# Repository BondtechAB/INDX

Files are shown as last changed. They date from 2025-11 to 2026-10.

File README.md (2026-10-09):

# INDX Wiki

> The community knowledge base for the Bondtech INDX, an induction-based automatic tool changer for open-platform XY-head 3D printers.

---

## Table of Contents

**Part 1: What is INDX?**

1. [What is INDX?](#what-is-indx)
2. [How It Works](#how-it-works)
3. [Kits & What's in the Box](#kits--whats-in-the-box)
4. [Supported Printers](#supported-printers)
5. [Technical Specifications](#technical-specifications)
   - [Part Cooling](#part-cooling)

**Part 2: Getting Started**

6. [Requirements & Preparation](#requirements--preparation)
7. [Installation](#installation)
   - [Hardware Installation](#hardware-installation)
   - [Firmware Configuration](#firmware-configuration)
     - [Klipper / Kalico](#klipper)
       - [INDX macro files](#indx-macro-files)
       - [Required Klipper sections](#required-klipper-sections)
       - [Load cell probe](#load-cell-probe)
       - [Automated dock X measurement](#automated-dock-x-measurement-built-in)
       - [Homing override](#homing-order-important)
         - [Seat check](#seat-check)
     - [RRF (RepRapFirmware)](#rrf-reprapfirmware)
   - [Initial Startup](#initial-startup)

**Part 3: Configuration**

8. [Configuration](#configuration)
   - [Dock Position Calibration](#dock-position-calibration)
     - [Finding dock_y](#finding-dock_y-y-fully-seated-position)
     - [Finding dock_x](#finding-dock_x-x-tool-centre)
   - [Tool Offsets](#tool-offsets)
     - [Method 1: Print and adjust](#method-1-print-and-adjust-free-no-extra-hardware)
     - [Method 2: Nudge](#method-2-nudge-automatic-requires-small-hardware)
     - [Method 3: Nozzle camera + CAL_ONE/TWO/THREE](#method-3-nozzle-camera-most-precise-xy-higher-cost)
     - [Z offset: CAL_Z](#z-offset-calibration)
   - [Temperature & Induction Settings](#temperature--induction-settings)
   - [Speed & Acceleration](#speed--acceleration)

**Part 4: Day-to-day Use**

9. [Using INDX](#using-indx)
   - [Loading Filament into Tools](#loading-filament-into-tools)
   - [Performing Tool Changes](#performing-tool-changes)
   - [Slicer Setup](#slicer-setup)

**Part 5: Designing for INDX**

10. [Designing for INDX](#designing-for-indx)
    - [Dock Design](#dock-design)
    - [Part Cooling (custom)](#part-cooling-1)
    - [CAD Files & Templates](#cad-files--templates)

**Part 6: Maintenance, Support & Community**

11. [Maintenance](#maintenance)
    - [Nozzle clog: cold pull procedure](#nozzle-clog-cold-pull-procedure)
12. [Troubleshooting](#troubleshooting)
13. [FAQ](#faq)
14. [Community & Contributing](#community--contributing)

---

**Part 1: What is INDX?**

---

## What is INDX?

INDX (INduction Dynamic eXtruder) is Bondtech's automatic tool-changer system for FDM 3D printers. It enables printing with multiple materials, colors, or nozzle sizes in a single print, with near-zero purge waste and tool changes in around 14 seconds. Run two tools or ten; scale your setup as far as your build space allows.

Unlike filament-switcher systems, INDX is a true tool changer: each tool carries its own filament directly. There is no shared filament path and no purge block required.

Unlike traditional mechanical tool changers, INDX uses wireless induction heating, so the passive tools contain **no wires, no heaters, no thermistors, and no electronics**. This makes each tool dramatically cheaper and mechanically simpler.

INDX is sold by Bondtech as a **Development Kit** for open CoreXY printers. Prusa Research has built an official first-party integration for the **CORE One** and **CORE One L**, sold directly through Prusa.

| | INDX Development Kit | Prusa CORE One / CORE One L |
|---|---|---|
| **Sold by** | Bondtech ([bondtech.se](https://www.bondtech.se)) | Prusa Research ([prusa3d.com](https://www.prusa3d.com)) |
| **For** | Most CoreXY printers with open firmware | Prusa CORE One / CORE One L |
| **Setup** | Self-managed (community-supported) | Plug-and-play |
| **Smart Head** | See [bondtech.se](https://www.bondtech.se) | See [prusa3d.com](https://www.prusa3d.com/applications/prusa-3d-printers-with-bondtech-indx_243519/) |
| **Passive Tools** | See [bondtech.se](https://www.bondtech.se) | See [prusa3d.com](https://www.prusa3d.com/applications/prusa-3d-printers-with-bondtech-indx_243519/) |

This wiki focuses on the **INDX Development Kit** and community integrations. For the Prusa integration, refer to [Prusa's documentation](https://www.prusa3d.com/applications/prusa-3d-printers-with-bondtech-indx_243519/).

---

## How It Works

INDX is built around two components: a single active **Smart Head** that stays on the gantry, and a set of interchangeable **Thin Passive Tools** parked in a dock.

### Smart Head

The single active unit that travels on the gantry. Contains all expensive and active components:

- **Induction coil (IN)**: wirelessly heats the nozzle of whichever passive tool is currently mounted on the Smart Head.
- **IR thermopile sensor**: reads nozzle temperature without physical contact. Also reports ambient temperature and nozzle surround temperature for monitoring.
- **Dynamic eXtruder (DX)**: self-adjusting dual-drive extruder with automatic tension mechanism.
- **Load cell**: used for sensing tool/nozzle touch.
- All wiring, electronics, and motion stays here; nothing transfers to the passive tools

### Thin Passive Tools

Interchangeable tools parked in a dock within reach of the gantry. Each tool contains a filament path and a specially designed nozzle, and nothing else. No wires, no heaters, no thermistors, no electronics. Heat is delivered wirelessly by the Smart Head's induction coil when the tool is picked up; the tool cools passively when deposited back in the dock.

Two variants are available, both built from steel:

- **CHT (Core Heating Technology)**: splits filament into three strands internally for faster melting and higher flow rates. The standard choice for most materials except abrasive materials. Available in common sizes.
- **Standard (non-CHT)**: straight-through melt zone with lower back-pressure, optimized for soft flexible filaments (TPU, TPE).

Tools are held in the Smart Head by a high-precision **Maxwell coupling** (a 3-point kinematic coupling that self-aligns the tool to the exact same position every time it is picked up), ensuring micron-level repeatability on every tool change. In practice this means you calibrate your tool offsets once, and they stay correct across thousands of tool changes.

### Tool Change Sequence

1. Smart Head moves to the dock and deposits the current tool
2. Smart Head picks up the next tool
3. Induction coil heats the new nozzle to printing temperature (~4-10 seconds)
4. Printing resumes

**Total tool change time: ~14 seconds**, depending on temperature delta, priming, and travel distance.

Because every material runs in its own dedicated nozzle, there is no cross-contamination between materials; purging is not required. The only material used after a tool change is a small **prime** at the start of printing: when a nozzle heats up, the filament in the melt zone re-melts and pressure needs to be rebuilt before extrusion is consistent. Priming pushes a small amount of filament through to establish that pressure, ensuring the first line of print is correctly extruded. Because each tool also cools passively when separated from the Smart Head, oozing is minimal.

---

## Kits & What's in the Box

### Development Kit

The INDX Development Kit comes as a **base kit** (the core hardware you need to get started) plus **tools** and **accessories** you choose to match your printer and setup.

#### What's in the box

Every Development Kit includes:

| Component | Description |
| --- | --- |
| **Bondtech INDX Smart Head** | The active unit: induction coil, contactless IR temperature sensor, DX extruder, and all electronics. One per printer. **Does not include a Thin Passive Tool**; tools are ordered separately. |
| **Bondtech INDX Link Board** | USB/CAN bridge between your host computer and the Smart Head. Includes 330 mm AWG18 power cables with horseshoe connectors for PSU screw terminals. A USB cable from the Link Board to your host is not included; see [Link Board](#link-board) for requirements. |
| **Crimp & connector kit** | Crimps and connectors for terminating accessories to the Bondtech INDX PCB: part cooling fan, LED, endstop, and USB devices. |

#### Tools

Thin Passive Tools are the interchangeable tool heads that do the actual printing. Choose quantity, nozzle type, and nozzle size when ordering. You need at least one tool to print, and one per material or color you want to run simultaneously.

| Option | Nozzle sizes | Best for |
| --- | --- | --- |
| **CHT (Core Heating Technology)** | 0.4 / 0.5 / 0.6 / 0.8 / 1.0mm | Most materials: PLA, PETG, ABS, ASA, TPU, TPE, PVA, BVOH, HIPS, PC, Nylon, PP, PBT, unfilled PC blends, and other non-abrasive filaments |
| **Standard (non-CHT)** | 0.25 / 0.4mm | Flexible filaments (TPU, TPE) and sensitive composites |

See [Thin Passive Tools](#thin-passive-tools) in the Technical Specifications for full details on each variant.

#### Accessories

Select the accessories that match your printer when ordering:

| Accessory | Options | Notes |
| --- | --- | ----- |
| **Bondtech INDX Link Cable** | Choose length | XT30 2+2 cable (24V, GND, CAN+, CAN−) with a shield connected to GND on the Link Board, from the Link Board to the Smart Head. Red/black wires carry power, yellow/white carry CAN H/L. Choose the length that fits your wiring run. See note below. |
| **Tool Dock** | Pre-made SLS hardware or STL/STEP files | Bondtech's ready-made docks are designed for MakerBeam XL 15×15. Or download the files and print your own; the standard 1515 body suits both profiles. |
| **X-Carriage adapter** | MGN12H option for 6mm belts, or download files | Required to mount the Smart Head to your carriage. Available for common CoreXY standards; check the shop or download from GitHub. |

> **What is CAN bus?** CAN bus is a communication standard that lets multiple devices share a single cable. You don't need to understand the protocol in depth; the Link Board handles it for you. In practice it means the Smart Head connects to the Link Board via just one 4-wire cable (carrying both power and data) instead of the bundle of wires a conventional toolhead needs. CAN is currently only supported on RRF; USB is used for Klipper/Kalico.
>
> **Choosing cable length:** Measure the wiring run from your Link Board mounting location to the Smart Head along the actual path the cable will travel (over the gantry, not straight-line). Add some slack. When in doubt, order longer. A cable that is too short cannot be extended, and excess length can be coiled and managed.

> **Integration note:** The Development Kit does not include a pre-configured printer profile or plug-and-play setup. You are responsible for integrating INDX with your printer's firmware and mechanics. The community provides configs and guides for common platforms; see [Supported Printers](#supported-printers) and [Community & Contributing](#community--contributing).

---

## Supported Printers

### First-party integrations

Prusa Research has built an official first-party integration for their CoreXY printers. These are sold and supported directly by Prusa, not through the INDX Development Kit.

| Printer | Status | Notes |
| --- | --- | ----- |
| Prusa CORE One | Available | Sold by Prusa Research. Plug-and-play. Supports up to 8 tools. See [prusa3d.com](https://www.prusa3d.com/applications/prusa-3d-printers-with-bondtech-indx_243519/) for details. |
| Prusa CORE One L | Coming later | First-party Prusa integration, availability timeline TBD. Supports up to 8 tools. |

### Officially recognized integrations

Beyond the first-party Prusa integration, a few community-built integrations are solid enough that Bondtech points people at them by name. Each comes with ready-to-print parts and the installation files needed to mount INDX on that machine.

They are not Bondtech products. They are hosted externally and maintained by their designers, so questions about the parts themselves belong with them rather than in this repository. Recognized here means we rate the work, not that we support it.

| Printer | Designer | Files |
| --- | --- | ----- |
| Sovol SV08 OG & SV08 Max | 3DPrintDemon | [Printables](https://www.printables.com/model/1771164-official-indx-sovol-sv08-og-sv08-max-integrations) |
| Voron Trident R2 | Steve — Voron team, designer of the Trident | [Printables](https://www.printables.com/model/1761163-trident-r2-bondtech-indx-mods) |

### Unverified community builds

INDX runs on a wide range of CoreXY printers, far more than Bondtech could ever test and support directly. What makes that possible is community members who've done the integration work on their own printer and shared what they learned. The printers below are known to work; what varies is whether anyone has published parts for them yet.

> ⚠️ **Nothing in this table has been checked by Bondtech.** We have not printed these parts, measured them, or run them on a machine here. Listing a build is not an endorsement and says nothing about whether the geometry is right. Read them the way you would read any stranger's remix: check a dock against [Dock Design](#dock-design) before printing it, since dock geometry that misses those constraints gives unreliable tool changes rather than an obvious failure. Questions about these parts belong with whoever made them, not with Bondtech.

| Printer | Build | Source |
| --- | ----- | --- |
| Voron 2.4 | Full conversion parts set: X-carriage, tool holder, XY joint, front idlers, Z bearing block with Y endstop, Z chain mount | [karasgit/INDX-for-Voron-2.4](https://github.com/karasgit/INDX-for-Voron-2.4), with a [walkthrough video](https://www.youtube.com/watch?v=topIOL-b3Gw) by Emplikac 000 |
| RatRig V-Core | None published yet | — |
| Custom CoreXY | None, and none expected: mounting is specific to your machine | Any CoreXY with open firmware works; see [Requirements](#requirements--preparation) |

The [Bondtech Discord](https://discord.gg/XDX9jDXN6e) has channels for specific printers, which is the best place to find someone running the same platform and ask how far along they got.

**Your printer isn't listed?** If you've got INDX running on it, that integration belongs here. Submit a pull request on [github.com/BondtechAB/INDX](https://github.com/BondtechAB/INDX) and you'll save the next person hours of work. See [Contributing a printer integration](#contributing-a-printer-integration) for what to include.

---

## Technical Specifications

*Specifications are preliminary and subject to change.*

### Smart Head

| Specification | Value |
| --- | ----- |
| Maximum operating voltage | 24V |
| Maximum nozzle temperature | 300°C |
| Maximum ambient operating temperature | 60°C |
| Flow rate | 40mm³/s *(measured at 220°C with 25°C ambient; lower rates achievable depending on nozzle size)* |
| Nozzle heat-up time | ~4-8 seconds |
| Tool change time | ~14 seconds *(highly dependent on temperature, priming, and travel distance)* |
| Power consumption | ~60W |
| Tool change mechanism | Maxwell coupling (3-point kinematic) |
| Heater type | Induction coil |
| Temperature sensor | Wireless & contactless IR thermopile |
| Nozzle sensor | Load cell (bi-directional) |
| Extrusion system | Direct Drive |
| Filament pre-tension | Self-adjusting (DX extruder, dual-drive with automatic tensioning) |
| Extruder chassis material | Aluminium |
| Cowling material | SLS-printed PA12 |
| Minimum tool center-to-center distance | 34mm bare; **41mm** with Bondtech part cooling solutions |
| Weight | 345g *(including one tool)* |
| Dimensions | See [reference geometry](#cad-files--templates) |

### Part Cooling

INDX uses a modular part cooling system. Cooling solutions snap onto the outside of the Smart Head cowlings, making it easy to swap between setups without tools. Three options are supported:

| Option | Description |
| --- | --- |
| **Dual 40×10 fans** | Two radial blower fans mounted symmetrically for balanced airflow around the nozzle |
| **CPAP** | High-flow airflow from a remote CPAP blower unit, routed via a flexible tube to the Smart Head, keeping weight off the gantry |

The right choice depends on your materials and print speed requirements. The dual 40×10 connect to the part cooling fan output on the Bondtech INDX PCB. The CPAP blower is a remote unit mounted elsewhere on the printer and connects to your main board instead; only the airflow tube routes to the Smart Head.

Printable ducts for both options are available in [CAD Files & Templates](#cad-files--templates).

### Bondtech INDX PCB

The Bondtech INDX PCB is mounted inside the Smart Head and is the central electronics board for the system.

**Electronics**

| Specification | Value |
| --- | ----- |
| Stepper driver | TMC2240 |
| Stepper run current | 0.6A |
| Extruder rotation distance | 5.7mm |
| Built-in accelerometer | LIS2DW |
| Built-in rotary encoder | AS5047D (magnetic) |
| Built-in load cell | *(specifications to be confirmed)* |

**Connectors**

| Connector | Pins | Notes |
| --- | ---- | ----- |
| Motor | Coil A+, Coil A−, Coil B+, Coil B− | DX extruder stepper motor |
| Fan | TACHO, FAN+, GND | Supports tachometer feedback |
| LED | 5V (VBUS), NP OUT, GND | NeoPixel compatible |
| Endstop | 3V3, SIGNAL, GND | 3.3V logic level |
| USB | VBUS, DP+, DP−, GND, GND | Supports accessories such as camera or Beacon probe scanner. **The DP+/DP− silkscreen is swapped — see [USB data pins](#usb-data-pins-are-swapped)** |
| CAN termination jumper | — | Enable/disable CAN bus termination |
| CAN Reset jumper | — | Puts the board into DFU mode for firmware flashing; remove after flashing |
| Communication switch | CAN / USB | Selects between CAN-FD and USB communication modes; must match the switch position on the Link Board |

**Status LEDs**

| Label | Colour | Meaning |
| ----- | --- | --- |
| VIN | Blue | 24V power present |
| 3V3 | Green | 3.3V onboard regulator active |
| ACTIVITY | Green | CAN-FD bus activity (other than regular time-sync messages) |
| STATUS | Red | Flashes at ~1Hz in sync with the main board = CAN time sync OK; rapid continuous flashing = no CAN sync; startup error codes (see table below) |

On first boot or after a failed flash, the STATUS LED may flash a startup error code rather than the normal 1Hz pattern. The pattern is: slow blinks (group 1) pause, then fast blinks (group 2). If this happens, reflash the firmware.

**Startup error codes**

| Error | Slow blinks | Fast blinks | Description |
| ----- | --- | --- | --- |
| ErrorTempMin | 1 | 1 | Measured temperature too low |
| ErrorTempMax | 1 | 2 | Measured temperature too high |
| ErrorTempAmbientMin | 1 | 3 | Ambient temperature too low |
| ErrorTempAmbientMax | 1 | 4 | Ambient temperature too high |
| ErrorTempDiff | 1 | 5 | Requested temperature differs significantly from measured temperature |
| ErrorHeatMax | 2 | 1 | Heater on at max power for too long |
| ErrorHeatInput | 2 | 2 | Heater enable request active for too long |
| ErrorInternalTemp | 5 | 3 | IR sensor self-test failed at boot |
| ErrorInternalUart | 5 | 4 | Internal UART fault |
| ErrorInternalEnable | 5 | 5 | Internal enable fault |

**Front INDX LED states**

The Smart Head uses a NeoPixel-compatible LED array on the front face to communicate its current state during normal operation. These are the same LEDs that display startup error codes.

| State | Colour | Pattern |
| ----- | --- | --- |
| Heating | Amber (RGB 255, 191, 0) | Breathing at 0.5 Hz (sine); brightness starts at 0 and increases as temperature approaches target |
| Cold / at ambient | Green | Solid |
| At target temperature | Amber | Solid |
| Cooling down from hot | Blue | Solid |
| DFU (firmware update) mode | Blue | Blinking |
| Load cell transient (filament gripped) | Purple | Single fast flash (~200 ms), then returns to previous state; effect is suppressed while the stepper motor is energised |

**FFC cable warning**

The Smart Head contains two PCBs (INDX VF PCB and INDX MCU PCB) connected by 20-way FFC (Flexible Flat Cable) connectors. If you ever need to disconnect and reconnect them during servicing:

- Insert the cable straight; inserting at an angle is easy to do and will short pins. Powering up with a shorted FFC will likely damage the board.
- The latch direction on the INDX MCU PCB FFCs is counter-intuitive: the latch is **unlocked when up**. After inserting the cable, push the latch **down toward the PCB** to lock it.

### Link Board

Bondtech INDX Link Board

The Link Board is a required component of every INDX Development Kit setup. It sits between your host computer and the Smart Head, acting as the USB/CAN bridge and providing several protection features that make the connection stable and safe.

**Why the Link Board is required**

The Link Board caps USB communication speed to **12 Mbps (Full Speed)**. While this is lower than the theoretical USB 2.0 maximum, it is intentional: Full Speed USB is dramatically more stable in electrically noisy printer environments than High Speed (480 Mbps). In practice this means fewer dropouts and disconnects, and a much more reliable connection to the Smart Head.

**Protection features**

| Feature | What it does |
| --- | --- |
| **USB isolator** | Electrically isolates the Smart Head from your host computer. Any electrical fault or noise on the printer side cannot travel back through the USB cable to your Raspberry Pi or PC. |
| **Reverse polarity protection** | Prevents damage if the 24V power input is connected with reversed polarity. |
| **4A fuse** | Protects the power input. If something goes wrong on the 24V side, the fuse blows before damage can propagate further. |

**Communication switch**

The Link Board has a switch to select between **USB** and **CAN** communication modes. This must match the switch position on the INDX MCU PCB inside the Smart Head — both boards must be set to the same mode, or the connection will not work. See [Switch configuration](#3-wiring) for reference images showing the correct switch positions on the Smart Head side.

**USB cable (not included)**

A USB cable from the Link Board to your host computer is not included and must be sourced separately. Requirements:

- **Data cable, not a charge-only cable.** Charge-only cables omit the data lines entirely and will not work. Verify the cable is rated for data transfer before using it.
- **Correct impedance.** The cable must meet USB signal integrity requirements. Cheap or poorly made cables can cause dropouts even at Full Speed. Use a cable from a reputable brand.
- **Total USB run ≤ 2 meters.** The combined length of your USB cable (host to Link Board) and your INDX Link cable (Link Board to Smart Head) must not exceed 2 meters. Plan your cable routing and Link cable length selection with this in mind.

**Specifications**

| Specification | Value |
| --- | ----- |
| Host connection | USB-C |
| Printer-side connection | Link cable to Bondtech INDX PCB |
| Input power | 24V + GND from PSU |
| Included power cables | AWG18, 330mm, horseshoe connectors for PSU screw terminals |
| USB speed | 12 Mbps (Full Speed) |
| Fuse rating | 4A |
| Max total USB run | 2 meters (USB cable + Link cable combined) |

### Thin Passive Tools

All Thin Passive Tools are built from steel, contain no electronics or wiring, and use induction heating via the Smart Head. Two variants are available:

**CHT (Core Heating Technology): Standard choice for most materials**

Uses Bondtech's patented CHT internal geometry, which splits filament into three thinner strands for faster melting and higher flow rates. Recommended for PLA, PETG, ABS, ASA, TPU, TPE, PVA, BVOH, HIPS, PC, Nylon, PP, PBT, unfilled PC blends, and other non-abrasive filaments.
Not recommended for soft flexible filaments.

| Specification | Value |
| --- | ----- |
| Available nozzle sizes | 0.4 / 0.5 / 0.6 / 0.8 / 1.0mm |
| Material | Steel |
| Compatible filament diameter | 1.75mm |
| Maximum nozzle temperature | 300°C |
| Electronics | None |
| Weight | 25g |

**Standard (non-CHT): For flexible and sensitive materials**

Uses a straight-through melt zone with minimal back-pressure, specifically optimized for soft flexible filaments (TPU, TPE) and sensitive composites. Built to the same steel standard.

| Specification | Value |
| --- | ----- |
| Available nozzle sizes | 0.25 / 0.4mm |
| Material | Steel |
| Compatible filament diameter | 1.75mm |
| Maximum nozzle temperature | 300°C |
| Electronics | None |
| Weight | 25g |

---

**Part 2: Getting Started**

---

## Requirements & Preparation

If you've built a Voron or a similar CoreXY printer from scratch, you have the skills needed to install INDX. The process involves editing Klipper config files, SSH access to your host computer, and careful mechanical alignment. Nothing beyond what a first-time Voron builder will have already done.

### Printer Requirements

For the Development Kit, your printer must meet these minimum requirements:

- **Motion system:** CoreXY, H-bot, Markforged, Cartesian XY-head, or similar. Supported: any motion system where the toolhead moves in XY and Z is handled by the bed or gantry — i.e. CoreXY (not cross-gantry), H-bot, Markforged, and independent-axis Cartesian (XY-head, e.g. Ender 5). Not supported: bed-slinger Cartesian (XZ-head), where the bed moves in Y, or Positron-style machines.
- **Firmware:** Kalico (recommended — native INDX support built in), Klipper, or RepRap Firmware (RRF)
- **Gantry clearance:** 50mm X, 44mm Y. Total toolhead height is ~152mm including strain relief. Additional clearance is required for umbilical and filament management.
- **Dock mounting area:** Each dock is ~70mm tall, 28.5mm wide (X), and 25mm deep (Y). Minimum tool center-to-center spacing is 34mm bare, or 41mm when using the Bondtech part cooling solutions.
- **Wiring:** 24V from the PSU to the Link Board (AWG18 horseshoe-connector cables included). Host computer to Link Board via USB-C or CAN. Link Board to Smart Head via INDX Link Cable (XT30 2+2, carries 24V, GND, CAN+/−, and shield).
- **Print volume impact:** Depends on printer geometry. Printers with sufficient Y overtravel may lose nothing. With a well-designed integration the worst case is 28.5mm of Y travel; avoid designs that exceed this.

### Electrical Requirements

INDX uses two boards: the **Bondtech INDX PCB** (inside the Smart Head) and the **INDX Link Board**.

**Bondtech INDX PCB**

The Bondtech INDX PCB is the central electronics board inside the Smart Head. It consists of two parts connected internally:

- **INDX VF PCB**: handles induction heating, contactless IR temperature sensing, and the heatsink fan
- **INDX MCU PCB**: handles all processing and communication: extruder motor control, accelerometer, load cell, CAN-FD communication, and the external connectors

All electronics are pre-installed inside the Smart Head; no internal wiring required. The Smart Head connects to the Link Board via a single INDX Link Cable (24V, GND, CAN H/DP+, CAN L/DN−, shield to GND) and exposes the following connectors:

- **Motor**: 4-pin, drives the DX extruder (TMC2240 driver). Pin 1 Coil A+, Pin 2 Coil A−, Pin 3 Coil B+, Pin 4 Coil B−
- **Endstop**: 3-pin, 3.3V logic level. Pin 1 3V3, Pin 2 SIGNAL, Pin 3 GND
- **Fan**: 3-pin, supports tachometer feedback. Pin 1 TACHO, Pin 2 FAN+ (PWM 24V), Pin 3 GND
- **LED**: 3-pin NeoPixel. Pin 1 5V (VBUS), Pin 2 NP OUT, Pin 3 GND
- **USB**: 5-pin, supports accessories such as a camera or Beacon probe scanner. Pin 1 VBUS (5V), Pin 2 DP+, Pin 3 DP−, Pin 4 GND, Pin 5 GND. **The DP+ and DP− labels are swapped relative to the actual signals — see [USB data pins](#usb-data-pins-are-swapped) before wiring anything to this connector**
- **Built-in accelerometer**: for resonance measurement and automatic input shaper calibration in Klipper
- **CAN termination jumper**: fitting the jumper enables the 120 Ω end-of-line termination resistor. Fit only on boards at the physical ends of the CAN bus.
- **CAN reset jumper**: Klipper: short the jumper to enter DFU mode for flashing. RRF: fit the jumper for CAN reset (also resets the CAN address). See the [Duet INDX Toolboard documentation](https://docs.duet3d.com/en/Duet3D_hardware/Duet_3_family/INDX_Toolboard).
- **Status LEDs**: 3V3, VIN, STATUS, ACTIVITY

Induction heating and contactless IR temperature sensing are handled internally by the INDX VF PCB; no additional wiring or configuration needed.

Bondtech INDX PCB pinout

##### USB data pins are swapped

> ⚠️ **The DP+ and DP− labels on the USB connector are wrong.** The pin marked **DP+ is electrically DP−**, and the pin marked **DP− is electrically DP+**. This applies to the silkscreen, the pinout image above, and the pin tables in this document. Wire by function, not by label.

So a USB accessory connects like this:

| INDX pin | Marked | Actually is | Connect to |
| --- | --- | --- | --- |
| 1 | VBUS | VBUS (5V) | 5V |
| 2 | DP+ | **DP−** | DATA − |
| 3 | DP− | **DP+** | DATA + |
| 4 | GND | GND | Ground |
| 5 | GND | GND | — |

For a Cartographer V4, whose own wiring guide lists black = Ground, green = DATA +, white = DATA −, that means green goes to the pin marked DP− and white goes to the pin marked DP+. Two users independently found that wiring by the printed labels fails to enumerate and that swapping the pair works.

If a USB accessory isn't detected at all, this is the first thing to check.

**Klipper pin → port mapping** (not exposed in RRF)

| Function | Port(s) |
| --- | --- |
| Motor | STEP `PB12` · DIR `PB23` · ENN `PB4` · CS `PA10` · SPI1 SCLK `PA5` / MOSI `PA4` / MISO `PA7` |
| Endstop | `PA9` |
| Part cooling fan | FAN `PA1` · TACHO `PA0` |
| Heatsink fan | FAN0 `PA21` · TACHO `PA20` |
| Neopixel | `PA8` |
| Eddy scanner | ldc_int `PB10` · ldc_clk `PB11` · temp_ldc `PB9` |

**Link Board**

The Link Board is required and bridges your host computer to the Smart Head. For full details on protection features, the communication switch, and USB cable requirements, see [Link Board](#link-board) in the Technical Specifications.

For wiring purposes:

- Requires **24V and GND** from your printer's power supply; connect using the included power cables (AWG18, 330 mm, pre-terminated with horseshoe connectors for screw terminal PSUs)
- Connects to the Smart Head via the INDX Link Cable
- Connects to your host computer via USB (cable not included — see [Link Board](#link-board) for requirements)
- The communication switch on the Link Board must match the switch on the INDX MCU PCB; both must be set to the same mode

**Power**

- The system runs on **24V**
- The Link Board is powered by a direct 24V/GND connection from your PSU
- Power is then passed through the Link cable (24V, GND, CAN+/D+, CAN−/D-) from the Link Board to the Smart Head; no additional PSU connection needed at the Smart Head

**Mainboard compatibility**

- Works with any printer running a Raspberry Pi, similar host computer or Duet board
- The Link Board connects to the host via CAN/USB; the host handles CAN/USB communication to the Bondtech INDX PCB

### Software Requirements

- **Kalico (recommended):** native INDX support is built in — nothing to install on the host, and the MCU firmware ships with Kalico. See [Firmware Configuration](#klipper).
- **Klipper (mainline):** add the [`indx_klipper`](https://github.com/BondtechAB/indx_klipper) module (installed with its `install.sh`), which brings the same INDX support to a stock Klipper install. See [Firmware Configuration](#klipper).
- RRF: RepRapFirmware **3.7.0-alpha (2026-02-10) or later**, required on both the main board and the Bondtech INDX PCB.
- Slicer: Any slicer with multi-filament or multi-color support

### Tools Required

| Tool | Use |
| ---- | --- |
| Hex keys | Smart Head, X-carriage adapter, and dock mounting |
| Crimping tool | Optional; only needed if connecting accessories (fan, LED, endstop, or USB devices) to the Bondtech INDX PCB |

### Skills Assumed

- Editing Klipper config files (`.cfg` syntax, adding sections, restarting Klipper)
- SSH access to your host computer (the [Connect via SSH](#connect-to-your-printer-via-ssh) section covers this if you need a refresher)
- Crimping JST and similar connectors

### What to Have Ready Before Starting

- A working printer, homed, printing, and confirmed stable before you begin
- Kalico (or Klipper / RRF) installed and running on your host computer
- SSH access to your host computer confirmed
- Spool holders and filament routing planned for the number of tools you intend to run

---

## Installation

> **Note:** These are general installation guidelines using the Bondtech-sold hardware as an example. Because INDX works across many different CoreXY printers, exact details (screw sizes, adapter geometry, carriage type, dock placement) will vary by printer. For printer-specific integration guides, check the [github.com/BondtechAB/INDX](https://github.com/BondtechAB/INDX) repository and the community resources in [Community & Contributing](#community--contributing).

### Hardware Installation

#### 1. Install the Smart Head

The Smart Head replaces your printer's existing toolhead entirely. It mounts to the X-axis carriage using a two-part system:

1. **X-carriage adapter**: bolts onto your carriage
2. **Smart Head**: attaches to the X-carriage adapter with 4 bolts

**X-carriage adapters** are available in two ways:

| Source | Material | Notes |
| --- | --- | --- |
| Bondtech (shop) | SLS-printed Nylon 12 GF | Common MGN12 carriage options available to purchase |
| GitHub / community | User-printed | Printable MGN12H adapter (6mm belts) in the repo; use the reference STEP to adapt one for other carriages |

If your carriage configuration isn't covered by Bondtech's sold options, the repository has a printable MGN12H adapter for 6mm belts in [CAD Files & Templates](#cad-files--templates). For anything else, the reference STEP in the same section carries the mounting geometry to design against, and the [officially recognized integrations](#officially-recognized-integrations) above cover some specific printers. Community-made X-carriage designs that meet quality standards are welcome in the repo via pull request.

> **Before you start:** Remove your existing hotend, part cooling fan, and any toolhead PCB or wiring mounted on the carriage. The Smart Head replaces all of this.

**Step 1: Mount the X-carriage adapter to the carriage**

Route and attach the belts behind the X-carriage, then attach the X-carriage adapter to your carriage block using the screws specified for your adapter. Tighten firmly but do not overtighten.

INDX MGN12H adapter mounting to rail, exploded view

INDX MGN12H adapter mounted on rail

**Step 2: Place the Smart Head onto the adapter**

Slide the Smart Head onto the X-carriage adapter so the mounting faces are flush.

Smart Head placed on X-carriage adapter

**Step 3: Secure the Smart Head**

Fasten the Smart Head to the adapter using 4 screws as specified for your adapter. Tighten firmly but do not overtighten.

Smart Head secured, rear view

Smart Head fully installed, front view

The Smart Head is now installed on the carriage.

**Attach part cooling**

Part cooling solutions snap onto the outside of the Smart Head cowlings. Attach your chosen cooling solution now before mounting the dock.

**Installing the fan shroud clip**

The clip is the interface between a fan shroud and the Front Cover, and there is a left and a right one: [`INDX_Part_Cooling_Interface_left.stl`](CAD/STL/INDX_Part_Cooling_Interface_left.stl) and [`INDX_Part_Cooling_Interface_right.stl`](CAD/STL/INDX_Part_Cooling_Interface_right.stl). Print both before starting, and repeat these steps for each side.

1. Loosen the screw that holds the INDX Front Cover.

   Loosen front cover screw

2. Use an M3×8 screw to secure the INDX Front Cover together with the fan shroud clip.

   Fan shroud clip installed

3. With the clip installed, attach the fan shroud to the Front Cover. The shroud has an upper tab that locates into a slot at the top of the Front Cover (highlighted in blue). Align the tab with the slot, then rotate the bottom of the shroud inward until it seats in position.

   Fan shroud mounted

#### 2. Mount the Dock

The dock can be positioned anywhere within the gantry's travel range, but the Smart Head must be able to face the docked tools directly to pick them up. The right location depends on your printer's layout.

**Frame requirement**

The dock must be mounted to a rigid bar or frame element; the dock hardware alone cannot be free-standing. Most CoreXY printers have an extrusion or crossbar that works for this. If your printer does not have a suitable mounting point, you will need to add one before proceeding.

The dock hardware Bondtech sells is designed for **MakerBeam XL 15×15**.

> 💡 **A note on fasteners.** MakerBeam XL has an indexing track running down the slot, so despite both profiles being 15×15 the two do not take a fastener quite the same way. The MakerBeam XL body still mounts fine on standard 1515 extrusion, so a ready-made dock or an already-printed MakerBeam XL body is not wasted if that is your frame. Standard T-nuts are the fiddly part: expect to shave a little material off one to clear the track. A printed M3 nut carrier for 1515 is the easier route if you have that body already.

If you are printing your own, the repository has two dock bodies. The **standard 1515** one suits both profiles, which makes it the easier all-round choice. See [CAD Files & Templates](#cad-files--templates). For any other frame, design your mounting to suit it.

> ⚠️ **Critical:** The dock has strict positioning requirements that must be met for reliable tool changes. Incorrect placement will cause failed pickups. See the critical requirements below before mounting.

**Dock options:**

| Source | Type | Mounting |
| --- | --- | --- |
| Bondtech (shop) | SLS-printed Nylon 12 GF | Designed for MakerBeam XL 15×15 |
| GitHub | Reference design + community designs | Print yourself, or adapt for your frame |

Community-contributed dock designs live in [`community/`](community/) in the repository. There is a [2020 extrusion dock](community/1_printer_agnostic/2020-dock/) there already if your frame is 2020 rather than 15×15, along with a [magnet jig](community/1_printer_agnostic/magnet-jig/) that makes dock assembly considerably less painful. If you design a dock for an unlisted printer or frame, consider submitting it. See [Dock Design](#dock-design) for geometry constraints and design requirements before you start.

**Critical dock positioning requirements**

**Height**

The dock must be positioned so that a parked tool sits **2mm higher** than it does when held in the Smart Head. This offset is what allows the Smart Head to pick up and deposit tools cleanly.

Dock height reference: 2mm offset between docked and picked-up tool position

**Alignment method**

Use the printable alignment jig ([`INDX_Dock_calibration_tool.stl`](CAD/STL/INDX_Dock_calibration_tool.stl)) placed over the nozzle tool in the toolhead to set the correct height. The printer does not need to be powered on for this step; you are setting the physical dock height manually.
_Pro tip: you can also use the alignment jig to get exact X alignment of the docks, by moving your printhead to the desired X value before doing the steps below._

1. Place the printed alignment jig over the tool magnets while the tool is in the smart head.

   Alignment jig fitted over the tool magnets on the Smart Head

2. Loosen the bar holding screws in order to let it be adjusted up and down, then slide the smart head toward the tool dock and make sure the alignment jig enters the magnet holes smoothly without the smart head nodding from mechanical strain.

   Alignment jig entering the tool holder magnet holes in the dock

3. Secure the dock bar at that height

#### 3. Wiring

Wiring up the Smart Head is unusually simple for a toolhead. On a conventional setup, you're running individual wires for the heater cartridge, thermistor, hotend fan, stepper motor, and any probes or sensors, each terminated, routed, and managed separately. With INDX, all of that is internal: the induction coil, IR temperature sensor, and heatsink fan are all handled inside the Smart Head with no external connections required. The only cable you run to the Smart Head is a single INDX Link Cable, four wires carrying 24V power and data.

The included **Link Board** acts as the bridge between your host computer and the Smart Head. Your host computer connects to the Link Board via USB (cable not included — see [Link Board](#link-board) for requirements), the Link Board connects to the Smart Head via the INDX Link Cable, and the Link Board receives 24V power from the PSU via the included AWG18 cables. That's the entire wiring run.

**Overview of connections:**

```
24V PSU ──────────────────────────────────────────────┐
                                                       │ 24V + GND
Raspberry Pi / host computer                           ▼
    │                                             Link Board
    └── USB ──────────────────────────────────────────►│
                                                       │
                                                       └── Link cable (24V, GND, CAN H/DP+, CAN L/DN−) ──► Bondtech INDX PCB (inside Smart Head)
                                                                                                           │
                                                                                                           ├── Motor (Coil A+, Coil A−, Coil B+, Coil B−)
                                                                                                           ├── Fan (TACHO, FAN+, GND)
                                                                                                           ├── LED (5V, NP OUT, GND)
                                                                                                           ├── Endstop (3V3, SIGNAL, GND)
                                                                                                           └── USB (VBUS, DP+, DP−, GND, GND)
```

**Switch configuration**

Before connecting the Link cable, set the communication mode switches on **both boards** to match: the switch on the INDX MCU PCB inside the Smart Head, and the switch on the Link Board. Both must be set to the same mode or the connection will not work.

Set both switches to **CAN** if you are using RRF. Set both to **USB** if you are using Klipper or Kalico.

INDX MCU PCB switch set to CAN mode
*Switch set to CAN mode*

INDX MCU PCB switch set to USB mode
*Switch set to USB mode*

#### 4. Flash the Bondtech INDX PCB

The Bondtech INDX PCB needs to be flashed with the correct firmware before the Smart Head can communicate with your printer. The flashing process differs depending on your firmware; follow the section for your setup.

##### Klipper / Kalico

Flashing is done over SSH from your computer into the Raspberry Pi (or other host computer) running Kalico or Klipper.

**What you need**

- **PuTTY**: a free SSH client for Windows. Download it from [its official site at chiark.greenend.org.uk](https://www.chiark.greenend.org.uk/~sgtatham/putty/latest.html), Simon Tatham's own page. `putty.org` is not affiliated with the project.
- Your printer's **IP address**: find this in your router's device list, or check the display on your host if it shows one. You can also use the hostname (e.g. `mainsailos.local` or `fluidd.local`) if your network supports it.

###### Connect to your printer via SSH

1. Open PuTTY
2. Enter your printer's IP address (or hostname) in the **Host Name** field
3. Make sure **Port** is set to `22` and **Connection type** is `SSH`
4. Click **Open**
5. Log in with your printer host credentials; the default username for most Klipper distributions is `pi` (Mainsail OS / FluiddPI) with the password you set during setup

You should now have a terminal prompt on your printer's host computer.

**Enter the bootloader**

Flashing happens while the Bondtech INDX PCB is in bootloader mode. If the board already has firmware, put it into the bootloader by fitting the **CAN RESET jumper** on the INDX MCU PCB while powering the board up. In bootloader mode the board enumerates on the host as a Microchip USB device (vendor `04d8`, product `e483`), identified as **"INDX Toolboard Bootloader"** by Bondtech AB. Confirm it is present with:

```bash
lsusb | grep 04d8:e483
```

**Kalico (recommended)**

Kalico ships with native INDX support built in — both the host module and the MCU firmware are part of the Kalico source tree, so there is nothing extra to install. Build and flash from your Kalico directory (usually `~/klipper`):

```bash
cd ~/klipper
KCONFIG_CONFIG=board_configs/bondtech_indx_usb.config make
KCONFIG_CONFIG=board_configs/bondtech_indx_usb.config make flash FLASH_DEVICE=04d8:e483
```

The `board_configs/bondtech_indx_usb.config` build config is included with Kalico. It preselects the SAME51 MCU, USB communication, and the INDX heater feature, so you don't need to run `make menuconfig`.

**Klipper (mainline)**

Mainline Klipper does not include INDX support. Add it with the `indx_klipper` module, then build and flash:

```bash
git clone https://github.com/BondtechAB/indx_klipper.git
cd indx_klipper
./install.sh /home/pi/klipper        # adjust the path to your Klipper install
make
make flash FLASH_DEVICE=04d8:e483
```

Once flashing is complete, remove the CAN RESET jumper (if you fitted one), power-cycle the Smart Head, and proceed to firmware configuration.

##### RRF (RepRapFirmware)

For RRF, flash and configure the Bondtech INDX PCB following the [Duet INDX Toolboard documentation](https://docs.duet3d.com/en/Duet3D_hardware/Duet_3_family/INDX_Toolboard).

#### 5. Load Passive Tools into the Dock

**Verify the Tool Dock Activator**

Before loading tools, check that the Tool Dock Activator is correctly installed. It is a small bracket mounted upright on the 15×15 mm aluminium extrusion using an M3×10 screw and an M3 nut. It must be perfectly vertical; this is the component that triggers the INDX latch mechanism during pickup.

Tool Dock Activator mounted on extrusion

Check that it is perpendicular to the extrusion:

Tool Dock Activator vertical alignment

**Load tools into the dock**

One passive tool fits in one dock position. Tools are retained by 3×8 mm bar magnets embedded in both the tool and the dock. The magnets naturally guide the tool into the correct orientation as you bring it close; follow the magnetic pull to seat it.

Passive tool loaded in dock

> **Note:** You will set the exact dock position coordinates (`dock_y` and `t*_x`) during the calibration steps later. For now, just seat the tools; the INDX macros handle the rest once configured.

---

### Firmware Configuration

#### Klipper

INDX's host-side support provides everything your printer needs to talk to the Smart Head: the `indx` temperature sensor, induction-heater control, extruder and accessory pin mapping, and the calibration commands. How you add it depends on your firmware:

- **Kalico (recommended):** support is **built in**. There is nothing to install on the host — the `[indx]` object and the `indx` sensor type are part of Kalico, and the MCU firmware ships with it too. Once you've flashed the Bondtech INDX PCB from the Kalico tree (see [Flash the Bondtech INDX PCB](#4-flash-the-bondtech-indx-pcb)), go straight to configuring your printer.
- **Klipper (mainline):** install the [`indx_klipper`](https://github.com/BondtechAB/indx_klipper) module, which adds the same host-side support to a stock Klipper install. Clone it and run its `install.sh` (see [Flash the Bondtech INDX PCB](#4-flash-the-bondtech-indx-pcb) for the commands).

The tool-change and calibration **macros** (`T0`/`T1`…, `PARK_TOOL`, the `CAL_*` helpers) are provided by the INDX macro package — see [INDX macro files](#indx-macro-files).

**Configure your printer**

After installing the plugin, add your INDX configuration to `printer.cfg`:

Add the following to your `printer.cfg`. The `serial` path under `[mcu indxmcu]` will be unique to your board; see the note below on how to find it.

```ini
[mcu indxmcu]
# Replace the serial path below with the one from your board — see "Finding your serial path" below
serial: /dev/serial/by-id/usb-Bondtech_INDX_<your-serial-here>

[indx]
mcu: indxmcu

# These are control parameters for the induction heater — leave them at these values
pid_kp: 1.0
pid_ti: 0.0
pid_td: 0.0
pid_b: 1.0

[extruder]
sensor_type: indx  # Custom sensor type provided by the INDX plugin — reads temperature via the IR sensor on the induction board
min_temp: 0
max_temp: 350
smooth_time: 0.3  # Reduce display and wait-condition lag during rapid induction heat-up

heater_pin: indx:heater
# Induction heating uses watermark (on/off bang-bang) control, not PID.
# This works well for induction because of its very fast response time. Do not change to pid.
control: watermark
nozzle_diameter: 0.4     # Change to match your passive tool nozzle size (0.4 / 0.6 / 0.8 / 1.0)
filament_diameter: 1.75

step_pin: indxmcu:motor_step
dir_pin: indxmcu:motor_dir  # If filament feeds backwards, change to: !indxmcu:motor_dir
enable_pin: !indxmcu:motor_enable
microsteps: 32
rotation_distance: 5.7  # Pre-calibrated for the DX extruder — do not change

[tmc2240 extruder]
cs_pin: indxmcu:motor_cs
spi_software_sclk_pin: indxmcu:motor_sclk
spi_software_mosi_pin: indxmcu:motor_mosi
spi_software_miso_pin: indxmcu:motor_miso
rref: 24000  # Reference resistor value for the TMC2240 on the INDX PCB — do not change
run_current: 0.6

[fan]
pin: indxmcu:part_cooling
tachometer_pin: indxmcu:part_cooling_tacho

[neopixel indx]
pin: indxmcu:led
chain_count: 16  # Fixed for the Smart Head LED array — do not change

[gcode_button endstop]
pin: ^indxmcu:endstop
press_gcode: {action_respond_info("press")}
release_gcode: {action_respond_info("release")}

[lis2dw]
# Built-in accelerometer on the INDX PCB — used for input shaper calibration
i2c_mcu: indxmcu
i2c_bus: sercom3

[angle indx]
# Magnetic encoder that reads extruder rotation — used for precise extrusion monitoring
sensor_type: as5047d
stepper: extruder
cs_pin: indxmcu:encoder_cs
spi_bus: sercom1
```

The INDX MCU reports nozzle temperature every 0.1 seconds. Klipper's default
one-second heater smoothing can nevertheless lag substantially behind the
measured temperature during the very fast induction heat-up, delaying the
displayed temperature and temperature-wait completion. Keep `smooth_time: 0.3`
in the extruder configuration to reduce that lag while retaining smoothing
across multiple reports.

> ⚠️ **Do not change `rotation_distance`**
>
> The `rotation_distance: 5.7` value is pre-calibrated for the DX extruder and is used by the INDX tool-change macros to calculate precise filament moves during tool changes. Changing it, even slightly, will cause incorrect filament positioning and failed tool changes. Do not treat it as a value to tune. If your extrusion multiplier needs adjusting, do it in the slicer, not here.

**Finding your serial path**

The `serial` value under `[mcu indxmcu]` is unique to your board. To find it, SSH into your printer (see [Connect to your printer via SSH](#connect-to-your-printer-via-ssh)) and run:

```bash
ls /dev/serial/by-id/
```

Copy the path that starts with `usb-Bondtech_INDX` and paste it into your config.

**Configuring multiple tools**

The `[extruder]` block above is always required and represents the Smart Head's single DX extruder. INDX passive tools are **not** separate Klipper extruders — there is only ever one `[extruder]`. Additional tools (T1, T2, …) are defined in `indx.cfg`: set `variable_tool_count` and add a `variable_t{n}_x` / `variable_t{n}_dock_y` pair per tool in the `[gcode_macro TOOL_POSITIONS]` section (see [INDX macro files](#indx-macro-files)). Per-tool XY/Z offsets come from [Tool Offsets](#tool-offsets) calibration, and per-tool nozzle sizes and temperatures are set in your slicer.

**Tools that do not print.** A dock position does not have to hold a hotend. If you are carrying a pen, a cutter, a camera or anything else with nothing to heat, list its tool number in `variable_no_heat_tools` in `indx.cfg`, for example `variable_no_heat_tools: [3]`. The pickup, latch and park moves already run cold, so the only thing that changes is that the induction coil is never switched on for that tool. Setting it here rather than in the slicer matters: your change filament G-code is a single template shared by every tool, so it will pass a temperature for the pen along with everything else, and this makes the printer ignore it. The tool still needs a dock position and still counts toward `variable_tool_count`.

##### INDX macro files

The INDX firmware plugin provides a set of `.cfg` files you include from `printer.cfg`. Each file has a specific role:

| File | Role |
| ---- | ---- |
| `indx.cfg` | User configuration: tool positions and related settings. **The only file you need to edit.** |
| `indx-tc-macros.cfg` | Tool change logic: `CHANGE_TOOL`, `PARK_TOOL`, boot detection. Do not edit. |
| `indx-cal.cfg` | Calibration macros: dock position, XY/Z offset calibration. |
| `homing.cfg` | `[homing_override]`: Y then X, load-cell seat check, then Z. Do not edit. |

Include them from your `printer.cfg`:

```ini
[include indx/indx.cfg]
[include indx/indx-tc-macros.cfg]
[include indx/indx-cal.cfg]
[include indx/homing.cfg]
```

Klipper allows only one `[homing_override]`. If your printer already has one (sensorless current, bed raiser, etc.), merge the INDX sequence into yours instead of including `homing.cfg` as-is.

##### Required Klipper sections

The INDX macros depend on a few stock Klipper modules. If any of these are missing from your `printer.cfg`, the macros will fail at runtime rather than at startup, which makes the cause hard to spot. Add all of them:

```ini
[save_variables]
filename: ~/printer_data/config/indx_vars.cfg

[respond]
```

`save_variables` stores the state INDX has to survive a restart: the active tool, latch state, per-tool XY/Z offsets, the toolchange counter, and the current speed mode. Without it every macro that reads `printer.save_variables.variables` errors out, and the printer forgets which tool is mounted across reboots. Point `filename` at any writable path in your config directory; the file is created for you.

`respond` provides the `RESPOND` command that every INDX macro uses for console output and prompts.

##### Load cell probe

The Smart Head's load cell is the printer's Z probe, so a `[load_cell_probe]` section is required too. The ADS131M02 that reads the load cell sits on the INDX toolboard, so its pins are addressed through the `indxmcu` MCU:

```ini
[load_cell_probe]
sensor_type: ads131m02
cs_pin: indxmcu:loadcell_cs
spi_bus: sercom1
data_ready_pin: indxmcu:loadcell_drdy
channels: 0
sample_rate: 500
z_offset: -0.15
force_safety_limit: 3200
trigger_force: 150
speed: 2
retry_speed: 1.0
lift_speed: 15
pullback_distance: 0.35
pullback_speed: 0.3
samples: 3
samples_result: median
sample_retract_dist: 0.35
samples_tolerance: 0.05
samples_tolerance_retries: 3
```

The pins are named aliases rather than raw MCU pins, so this config stays valid across INDX PCB revisions.

`trigger_force` is the contact force in grams that counts as a touch.

> ⚠️ **`z_offset` is a per-machine value, not a constant.** The nozzle is the probe, so there is no probe-to-nozzle distance to correct for, but the tool and Smart Head still deflect slightly under the trigger force before contact is registered. `z_offset` takes that out. The value above came from a working machine and is a reasonable starting point; treat it as something to tune for yours rather than a number to copy. Too little and your first layer sits high, too much and the nozzle digs in.

`pullback_distance` and `pullback_speed` control what happens immediately after contact: the toolhead retracts a short distance at a slow speed while the load cell keeps sampling, and the tap analysis uses that force curve to work out the exact moment the nozzle touched. Slower and shorter gives a cleaner curve; too slow and every probe costs noticeable time.

`samples: 3` with `samples_result: median` takes three probes and keeps the middle one, which throws out a single bad reading rather than averaging it in. That matters most for `G28 Z`, where one probe decides your Z origin. `CAL_Z` runs its own convergence and median sampling across many probes on top of this (see [Z Offset Calibration](#z-offset-calibration)), so the two are not redundant; the probe-level median cleans up each individual reading that the higher-level sampling then works from.

`speed: 2` and `retry_speed: 1.0` are slow on purpose. A faster approach overshoots the trigger point before the load cell reacts, which both marks the bed and reads high.

Two values are missing from the block above on purpose: `counts_per_gram` and `reference_tare_counts`. Those come out of [load cell calibration](#load-cell-calibration) and are written to the `SAVE_CONFIG` block at the bottom of your `printer.cfg` automatically. Don't set them by hand — run the calibration and let it fill them in.

> ⚠️ **This section is Kalico-specific.** Mainline Klipper also has a `[load_cell_probe]`, but it is a different implementation and does **not** accept `pullback_distance`, `pullback_speed`, `disable_pullback_move` or `drift_safety_limit`. On mainline Klipper, drop the two pullback lines; everything else above is common to both. Note also that mainline clamps `force_safety_limit` to a minimum of 100 where Kalico allows lower values, so a config written for one is not guaranteed to load on the other.

**Running a Beacon or Cartographer as well?**

The load cell registers itself as the printer's probe, so a scanning probe on the same machine has to be told not to. For Beacon, add both of these to your `[beacon]` section:

```ini
register_as_probe: false
prefixed_probe_commands: true
```

For Cartographer, add only the first line to `[cartographer]` — it will reject `prefixed_probe_commands`.

##### Eddy current scanner (optional)

The INDX toolboard has an LDC1612 eddy current scanner on board. It can scan bed meshes; Z homing stays on the load cell. This needs a Kalico build from 2026-10-08 or later (multiple probes, KalicoCrew/kalico#972, and `amplitude_errors`, KalicoCrew/kalico#1009).

```ini
[probe_eddy_current scanner]
sensor_type: ldc1612
i2c_mcu: indxmcu
i2c_bus: sercom3
intb_pin: indxmcu:ldc_int
# The toolboard clocks the LDC1612 from its 25 MHz crystal
frequency: 25000000
# Scanner position relative to the nozzle (Smart Head CAD)
x_offset: 0
y_offset: 34.472
z_offset: 1.0
# The load cell stays the default probe; the scanner is selected with PROBE=scanner
register_as_probe: False
# The INDX coil trips the LDC1612 amplitude-low error in normal use
amplitude_errors: high

# Scanner coil temperature, for monitoring
[temperature_sensor scanner_coil]
sensor_type: indx
indx_sensor: ldc_coil
```

Calibrate it once, with T0 on the head and the printer homed (`G28`):

1. `LDC_CALIBRATE_DRIVE_CURRENT CHIP=scanner`, then `SAVE_CONFIG`.
2. `G28` again, then `PROBE_EDDY_CURRENT_CALIBRATE CHIP=scanner`. Bring the nozzle down until it just touches the bed (the manual probe prompt), accept, and `SAVE_CONFIG`.

Scan a mesh with `BED_MESH_CALIBRATE PROBE=scanner`. Without `PROBE=` the mesh is probed with the load cell. In `[bed_mesh]`:

- `horizontal_move_z` must be above the scanner `z_offset` (for example 2), or every scanner probe starts already triggered.
- Mesh coordinates are scanner positions, and the nozzle is 34.5 mm further toward the front. Pick `mesh_min` Y so the nozzle stays at or behind `clearance_y` (with `clearance_y: 0`, `mesh_min` Y 35 or more).
- Set `zero_reference_position` to the G28 Z probe point (`probe_x`, `probe_y` in `indx.cfg`, or the bed centre). The mesh is then zeroed where the load cell set Z0, so the scanner only supplies the bed shape and its overall height drift cancels out.

If a wrapper macro (KAMP or your own `PRINT_START`) calls `BED_MESH_CALIBRATE`, make it pass `PROBE=scanner`.

##### Automated dock X measurement (built in)

Automated dock X measurement is **built into the INDX plugin** — there is no separate Python extra to install. The plugin registers `INDX_DOCK_MEASURE`, which energises the XY motors, homes Y then X from the dock, and derives the absolute dock position from the raw stepper counts (so it works for each tool in turn without a prior `G28`).

The `indx-cal.cfg` macros wrap this into the calibration commands you actually run:

| Command | Description |
| --- | --- |
| `CALIBRATE_DOCK_X TOOL=N` | Measures dock X for tool N via `INDX_DOCK_MEASURE` and reports the value to paste into `indx.cfg`; see [Dock Position Calibration](#dock-position-calibration) |
| `READ_DOCK_POSITION TOOL=N` | Reports the current (already-homed) X as dock X for tool N |

---

##### Homing order (important)

With a dock mounted on your printer, the default homing sequence can cause crashes. The Smart Head must move away from the dock before X is homed, and Z homing needs a seated tool (the load cell is the nozzle probe).

The INDX macro package includes a ready-to-use `[homing_override]` in `homing.cfg` that handles all of this. Its sequence, in full:

1. Raise to `probe_z_clearance` (set in `indx.cfg`). If Z is unknown, hop that height then un-home Z so the later probe is a real home.
2. Home Y. `G28 X` with Y unknown homes Y first.
3. Home X at a Y that clears the docks. Homing X crosses every dock position. If the head's Y (the Y endstop after a fresh Y home, or the current Y if Y was already homed) is on the dock side of `clearance_y`, it moves to `clearance_y` first; if it is already on the far side, for example a Y endstop opposite the docks, X homes where it stands. An unknown Y always moves. `dock_dir` in `indx.cfg` decides which side the docks are on.
4. Make T0 the tool on the head. `G28 Z` always homes on T0, because the per-tool Z offsets are stored as differences from T0. With T0 locked there is no dock trip; another tool is parked and T0 fetched; an empty head fetches T0, also when Z has never been homed (step 1 already lifted the gantry clear of the bed). Until the docks are measured (`docks_calibrated: False`), G28 refuses that trip: seat T0 by hand with `MANUAL_TOOL_SEAT TOOL=0` first. `home_check_seat` in `indx.cfg` decides how INDX knows what is on the head: `False` (default) trusts `active_tool`, `True` also requires the load cell to agree. See [Seat check](#seat-check) for what turning it on buys and costs.
5. Move to the probe XY (`probe_x` / `probe_y`, or bed centre), home Z, then lift back to `probe_z_clearance`. `G28 Z` ends at the trigger point a fraction of a millimetre off the bed, so the lift leaves the head at a height any following move can start from.

`CAL_Z` stores per-tool Z offsets relative to T0, which is why Z always homes on T0.

#### Seat check

Z homing probes with the nozzle, so it needs a tool on the head. The load cell can be asked to confirm one is there before every `G28 Z`, by setting `home_check_seat: True` in `indx.cfg`. It is off by default, and that default is deliberate.

The load cell is a dependable contact detector and an undependable scale. Probing only asks it *when* force changed, which it answers well. The seat check asks it *how many grams are on the head right now*, and that number moves with the tare. A head tared with a tool already in it reads near zero with that tool still seated, and the check then refuses a homing that would have been perfectly safe.

With the check off, `active_tool` answers instead. That is the same value every tool change already trusts, so the seat check is not the weak link if it is wrong. What you give up is the one place that could have caught it being wrong.

With the check on, the cell and `active_tool` must agree. Either can be wrong on its own, so a disagreement in either direction stops the machine and asks rather than picking a winner: a cell that reads empty while `active_tool` names a tool would otherwise send a loaded head into another dock. T0 is fetched only when both say the head is empty. Tune the threshold with `home_min_force_g` (default 800 g), and note that a missing or uncalibrated `[load_cell_probe]` becomes a homing error rather than just a probing one.

`INDX STATUS` prints the live reading on its `SEAT FORCE` line whichever way this is set, so you can see what the cell thinks without having it gate anything. If it reads near zero with a tool seated, the tare has drifted: run `CALIBRATE_LOAD_CELL` with an empty head.

If you use sensorless XY homing, wrap the `G28 Y` / `G28 X` steps in your usual TMC current reduce/restore (merge into the override if you already have one).

**Review your `PRINT_START` macro**

If you are migrating from a single-toolhead printer, your existing `PRINT_START` macro almost certainly heats the hotend before printing starts, something like `M104 S{first_layer_temperature}` or `M109 S{first_layer_temperature}`. With INDX, this will cause problems: there is no hotend to heat until a tool has been picked up by the Smart Head.

> ⚠️ Any hotend heating commands in your `PRINT_START` macro must come **after** the first tool pick-up. Sending a heat command before a tool is picked up will result in an error, and depending on your macro structure, may cause a crash or leave the printer in a bad state.

Review your `PRINT_START` macro and move all `M104`/`M109` (and any temperature wait commands) to after the first tool pick (`Tn` / `CHANGE_TOOL`). If you are writing a fresh macro, pick up a tool first, then heat.

INDX's own `M104` and `M109` (in `indx-tc-macros.cfg`) enforce this: with no tool on the head they don't heat and say so in the console, a tool listed in `no_heat_tools` is never heated, and `M104 T<n>` / `M109 T<n>` for a tool that is not on the head is ignored instead of stopping the print (slicers send these for parked tools). If your config defines its own `M104` or `M109`, only the last one loaded is used, so merge these rules into yours.

**Display alerts**

Warnings that are dangerous to ignore (`! ...`, for example a failed homing or `clearance_y` too close to a dock) and moments when you need to act (`> ...`, for example docks not calibrated yet) are also shown with `M117` on the printer display. The console keeps the full message. An INDX alert clears itself after the next successful `G28`, and never clears your own `M117` text.

#### Pickup and park checks

INDX checks every pickup and every park with the load cell. This is on by default (`seat_check_enabled: True` in `indx.cfg`) and is separate from the homing [seat check](#seat-check) above. Each check compares two readings taken standing still a few seconds apart, so the tare and the load cell's drift with temperature do not affect it.

- **Pickup.** The head reads the load cell at the trigger line with the head empty, picks up the tool, and reads it again. A seated tool adds its latch spring preload, so the two readings must differ by at least `seat_min_force_g` (default 680 g). If they don't and the difference is below `seat_empty_max_g` (default 230 g), the head is empty: the console says so, X and Y are homed again, and the tool is parked and picked up once more. In sport mode INDX first switches to normal tool change speed, says so on the console and the display, and stays in normal (also after a restart) until you run `MODE_SPORT` again. If the second try fails too, the heater is turned off and no tool is recorded. A difference between `seat_empty_max_g` and `seat_min_force_g` means the tool may be half seated on the head. INDX never assumes the head is empty, so there is no retry: the heater is turned off, the tool stays recorded as on the head, the latch is left as it is, and the display shows `T<n> may be on the head`. Until the head has been checked, `G28` (when it homes Z), `CHANGE_TOOL` and `PARK_TOOL` refuse to run, also after a restart. Check the head by hand, then run `MANUAL_TOOL_REMOVE` (take the tool off and put it in its dock) or `MANUAL_TOOL_SEAT TOOL=<n>` (it is fully on). Either one, or `MANUAL_TOOLHEAD_RESET`, clears the refusal. Either way, during a print the print pauses, with nothing moved or retracted: get the tool back in its dock with the head empty, run the `CHANGE_TOOL` command the console gives you, then `RESUME`. Outside a print, and during the T0 fetch of a `G28`, INDX stops with an error.
- **Park.** The head reads the load cell with the tool still seated, parks it, and reads it again after leaving the dock. The readings must differ by at least `park_min_change_g` (default 425 g). If they don't, the tool is probably still on the head: INDX stops with an error before driving anywhere else, turns the heater off, and keeps the tool recorded as on the head. Check the head. If the heater also reported a model divergence, a blob from a detached print may be stuck on the nozzle.

Successful pickups print the reading in the console, for example `T1 seated: load cell -1650 g against the empty head`, which is useful when tuning `seat_min_force_g`. A failed check also shows a short alert on the printer display.

Without a calibrated load cell the checks are skipped, with one line in the console after each restart. To turn them off, set `variable_seat_check_enabled: False` in `indx.cfg`. Tool changes then work as they did before the checks existed. If you keep your own `indx.cfg`, the checks are on with the defaults above until you add these settings.

#### RRF (RepRapFirmware)

Configure the Bondtech INDX PCB in RRF following the [Duet INDX Toolboard documentation](https://docs.duet3d.com/en/Duet3D_hardware/Duet_3_family/INDX_Toolboard).

The RRF tool-change and calibration macros are in [`macros/RRF/`](macros/RRF/) in this repository. They are the RRF counterpart to the Klipper `.cfg` files described above, covering tool changes (`tpreN.g`, `tpostN.g`, `tfreeN.g` for each tool, calling `INDX_TC_PRE.g`, `INDX_TC_POST.g`, `INDX_TC_FREE.g`, with `INDX_UNLOCK_DANCE.g` releasing a docked tool and `INDX_TC_REPORT.g` logging each check), the latch (`INDX_OPEN.g`, `INDX_CLOSE.g`, `INDX_CLOSE_CAL.g`, `INDX_LATCH_ENGAGE.g`, `INDX_LATCH_MOVE.g`), load-cell calibration, taring and readings (`INDX_LC_CALIBRATE.g`, `INDX_LC_CAL.g`, `INDX_LC_RETARE.g`, `INDX_TARE.g`, `INDX_LC_RAW.g`, `INDX_LC_SPEED_SWEEP.g`), the check that a tool is on before the nozzle probes (`INDX_TOOL_CHECK.g`), state persistence (`INDX_WRITE_STATE.g`), Z homing, bed levelling and meshing against the load cell (`homez.g`, `bed.g`, `mesh.g`), and pause, stop and power-loss resume (`pause.g`, `stop.g`, `resurrect-prologue.g`). `INDX_TC_TEST.g` is a test macro that cycles every tool and checks each drop-off and pickup; it goes in `0:/macros`.

Settings live in [`INDX_variables.g`](macros/RRF/INDX_variables.g), which is the RRF equivalent of `indx.cfg` and the file to edit. Call it from `config.g` with `M98 P"INDX_variables.g"` **after** the hardware configuration, including after the `M558`/`G31` that create the load-cell probe.

### Initial Startup

Before calibrating the dock or running any tool changes, verify that the Smart Head is communicating correctly and all connected components are working. Work through these checks in order before moving anything near the dock.

### 1. Verify MCU connection

Power on your printer and open Klipper (Mainsail or Fluidd). Check the MCU status in the interface; `indxmcu` should appear as connected.

If Klipper reports a timeout or cannot connect to `indxmcu`, the most common causes are:

- **Firmware not flashed**: the most likely cause on a first startup. If you haven't flashed the Bondtech INDX PCB yet, or the flash didn't complete successfully, go back to [Flash the Bondtech INDX PCB](#4-flash-the-bondtech-indx-pcb) before continuing
- **Incorrect `serial` path**: re-run `ls /dev/serial/by-id/` via SSH and confirm the path matches what's in `[mcu indxmcu]` in your config
- **Communication mode switch** not set correctly: confirm the switch on the INDX MCU PCB is set to CAN or USB to match your wiring. See [Switch configuration](#3-wiring) for reference images
- **INDX Link Cable** not fully seated at either end

Once `indxmcu` shows as connected, proceed.

### 2. Check extruder motor direction

With no filament loaded, issue a small extrude command from the Klipper console:

```gcode
G91           ; relative mode
G1 E10 F300   ; extrude 10mm
G90           ; back to absolute
```

> **Note:** If Klipper throws a "Cannot extrude — minimum extrude temperature" error, either heat the nozzle first (`M104 S200` and wait for it to reach temperature), or — on Kalico — allow cold extrusion at runtime with `M302 P1`. Run `M302 P0` to re-enable the protection once you've confirmed motor direction. No config change or restart is needed.

The extruder gear should turn in the direction that feeds filament through the tool. If it moves the wrong way, add `!` to the `dir_pin` in your `[extruder]` config and restart Klipper.

### 3. Check part cooling fan

If you have a part cooling fan connected to the Bondtech INDX PCB, trigger it from the console and confirm it spins:

```gcode
M106 S255   ; fan full speed
M107        ; fan off
```

Skip this step if you haven't connected a fan yet.

### 4. Verify accelerometer

The Bondtech INDX PCB has a built-in accelerometer; no external ADXL345 or similar sensor needed. Confirm it is responding:

```gcode
ACCELEROMETER_QUERY
```

You should see a stream of X/Y/Z acceleration values returned in the console. If you get an error, check the `[lis2dw]` section in your config for correct `i2c_mcu` and `i2c_bus` values.

### 4a. Run input shaper calibration (optional but recommended)

With the built-in accelerometer confirmed working, you can run Klipper's resonance testing to calibrate input shaper, with no external ADXL345 needed.

**Install the required Python dependencies**

These are not installed by default on most Klipper hosts. Run this once on your Pi:

```bash
sudo apt install python3-numpy python3-matplotlib libatlas-base-dev libopenblas-dev -y
~/klippy-env/bin/pip install numpy matplotlib --upgrade
```

Then restart Klipper:

```bash
sudo systemctl restart klipper
```

**Add the resonance tester config**

Make sure your config includes a `[resonance_tester]` section referencing the built-in accelerometer and a probe point near the centre of your bed:

```ini
[resonance_tester]
accel_chip: lis2dw
probe_points:
    <X_CENTER>, <Y_CENTER>, 20    # replace with your bed centre coordinates
```

> ⚠️ The built-in accelerometer on the INDX PCB is a **LIS2DW**, not an ADXL345. Use `accel_chip: lis2dw`, not `adxl345`.

**Run the tests**

Home the printer, then run one axis at a time from the Klipper console:

```gcode
TEST_RESONANCES AXIS=X
TEST_RESONANCES AXIS=Y
```

Klipper will move the toolhead through a frequency sweep and generate resonance data. Once both axes are done, run:

```gcode
SHAPER_CALIBRATE
```

This analyses the data and recommends input shaper settings. Apply the suggested values to your `[input_shaper]` section in your config, then save and restart Klipper.

> 💡 If `TEST_RESONANCES` returns an error about missing modules, the Python dependencies above were not installed correctly. Re-run the `apt install` and `pip install` commands and restart Klipper again.

### 5. First heat-up & heater calibration

The induction heater itself is controlled by a simple **on/off (watermark) loop**, which suits induction's very fast thermal response. Separately, the INDX board builds a **thermal model** of the nozzle and tool that it uses purely for **safety monitoring** — detecting a nozzle that isn't heating as expected, a tool pulled mid-heat, or a thermal runaway (these surface as the `ErrorTempDiff` / `ErrorHeatMax` conditions). The thermal model does not drive heating; it only supervises it. Before first use this model has to be calibrated. It is a one-time procedure per tool/cooling setup; the results are written to your config with `SAVE_CONFIG`.

> ⚠️ The nozzle gets hot during calibration. Pick up a tool first (`T0`) so a nozzle is present in the coil, and keep flammable material away from the Smart Head.

Run the commands in order from the Kalico/Klipper console:

| Command | What it does |
| --- | --- |
| `INDX_CALIBRATE` | Heats the nozzle through a controlled ramp and fits the thermal-model parameters (`max_power`, `thermal_capacity`, `to_ambient_r`) |
| `INDX_FAN_CALIBRATE` | Steps the part cooling fan through several speeds and models its cooling effect on the nozzle |
| `INDX_LOAD_FILAMENT` | Loads filament and measures its heat capacity so the model accounts for the energy the filament carries away (see below) |
| `SAVE_CONFIG` | Writes the calibrated values into your `[indx]` config section and restarts |

`INDX_CALIBRATE` and `INDX_FAN_CALIBRATE` characterise the nozzle/tool and the part cooling fan — run them once per tool type and cooling setup. Because these values feed the safety model rather than the control loop, don't hand-edit them afterwards; re-run the routine if the tool type or part cooling setup changes.

##### Calibrating a CPAP or other high-flow part cooling

CPAP blowers need more care than the dual 40×10 fans, and getting this wrong is the most common cause of a printer that runs fine until part cooling kicks in and then shuts down a minute later. That shutdown is the safety model working correctly: the fan is removing more heat than the model predicts, the divergence exceeds `max_model_error`, and the printer stops.

**Your fan must respond across the whole commanded range.** `INDX_FAN_CALIBRATE` fits a power law with a negative exponent:

```
part_cooling_fan_a × fan_speed ^ (−part_cooling_fan_k)
```

which means the fit is most sensitive at *low* fan speeds. If your fan config uses `off_below`, every commanded speed under that threshold sets the fan to zero, so the calibration records "5% commanded, no cooling measured" exactly where it matters most and the fitted curve is wrong across the entire range.

Use `min_power` rather than `off_below` for a blower. `min_power` rescales the commanded range onto the range the blower can actually turn in, so commanded speed keeps tracking real airflow all the way down:

```ini
[fan]
pin: ...
min_power: 0.14       # not off_below — set to your blower's real minimum
kick_start_time: 0.1
cycle_time: 0.0003
```

**Then calibrate in this order**, with the hose attached and the duct in its final configuration:

1. `INDX_CALIBRATE` with the part cooling fan **off**, to fit the base thermal model
2. `INDX_FAN_CALIBRATE BREAKS=50 MIN_SPEED=0.01 HOLD_TIME=20`, with the nozzle at print height (around 0.2 mm) over a clean build plate
3. `SAVE_CONFIG`

Both details in step 2 matter. Calibrating without the hose, or with the nozzle up in free air, measures airflow that doesn't match what the nozzle sees while printing — and the model is only as good as the conditions it was fitted in.

**Watch the fan through the sweep.** It should visibly change speed at every step. If it doesn't, the fan config is still truncating the low end and the fit will be wrong again no matter how many times you re-run it.

> ⚠️ **Don't raise `max_model_error` to stop the shutdowns.** A passive tool has no thermistor, so model divergence is the main thing standing between a misbehaving coil and a fire. Raising the limit hides the symptom and removes the protection. If the model keeps diverging, the fan calibration is wrong — fix that instead.

**Filament heat capacity.** Different filaments carry heat away from the nozzle at different rates, so the safety model also needs to know which filament is loaded. You set this when you load filament into a tool, not during the one-time calibration above:

- **Measure it** — `INDX_LOAD_FILAMENT` feeds and primes filament while measuring the actual heat capacity, then (with `APPLY=1`) writes it to your config. Most accurate; run `SAVE_CONFIG` to keep it.
- **Set it by type** — `INDX_SET_MODEL_PARAMS FILAMENT_DENSITY=… FILAMENT_HEAT_CAPACITY=…` applies known values for a material without measuring.

The `LOAD_FILAMENT` macro wraps both of these together with tool selection — see [Loading Filament into Tools](#loading-filament-into-tools).

**The model only uses the product.** Density and heat capacity are always multiplied together, never used separately, so how the value is split between the two doesn't matter — only that `density × heat_capacity` is right for the material. This is why a measured run reports `model_filament_density = 1.0000`: the measurement can only recover the product, so it pins density to 1 and folds everything into heat capacity. That isn't a failed measurement.

**Values are remembered per tool.** `LOAD_FILAMENT TOOL=n TYPE=…` records the filament against that tool, and every subsequent pickup of it restores those values before the tool heats. Without that, the model would keep whichever material was loaded last on any tool, which on a multi-material print is the wrong filament for most of the job. You can set it directly for a tool at any time:

```gcode
SET_TOOL_FILAMENT TOOL=1 DENSITY=1.21 HEAT_CAPACITY=1.80
```

Tools that have never been loaded through `LOAD_FILAMENT` or `SET_TOOL_FILAMENT` simply leave the model untouched on pickup.

> ⚠️ A measured run (`MEASURE=1`) applies its result globally rather than to the tool it measured, because the measurement is written by the firmware rather than the macro. After `SAVE_CONFIG` and a restart, record it against the tool with `SET_TOOL_FILAMENT TOOL=n DENSITY=1.0 HEAT_CAPACITY=<the measured value>` so it survives toolchanges.

---

**Part 3: Configuration**

---

## Configuration

### Load cell calibration

The Smart Head's load cell senses tool/nozzle touch and is the printer's **Z probe**, so it must be calibrated before the printer can home Z.

> ⚠️ **Do this before your first Z homing.** Z homing probes the bed with the load cell, so the load cell must be calibrated before a full `G28` — and therefore before dock and [Z-offset](#z-offset-calibration) calibration. It's a first-boot, by-hand step: **X and Y are homed first** (they don't use the load cell), but the tool is seated by hand because the dock can't be reached until Z is homed.

Start with **no tool on the Smart Head** and run:

```gcode
CALIBRATE_LOAD_CELL
```

This homes X and Y, opens the latch (and records soft-state Open), and tares the empty head. X and Y are not homed again if they already are, and an open latch is not opened again.

`CALIBRATE_LOAD_CELL` refuses to run when `active_tool` says a tool is on the head, or when an earlier calibration exists and the load cell reads a seated tool. Run `MANUAL_TOOL_REMOVE` and lift the tool off, or put it in its dock, then run it again. On a first calibration there is nothing to read against, so make sure the head is empty yourself.

Now **seat a passive tool on the Smart Head by hand** — the tool **must be empty** (no filament in the extruder gears) — then calibrate against the known locking force (default 1600 g). `CALIBRATE_LOAD_CELL_APPLY` locks, samples, then unlocks again so you can remove the tool by hand.

```gcode
CALIBRATE_LOAD_CELL_APPLY GRAMS=1600
SAVE_CONFIG
```

Prefer the console? Run `LOAD_CELL_CALIBRATE`, then `TARE` with no tool, seat an **empty** tool and lock the latch, then `CALIBRATE GRAMS=1600`, `ACCEPT`, unlock the latch, and `SAVE_CONFIG`.

Restart. Then put T0 on the head by hand and run `MANUAL_TOOL_SEAT TOOL=0` before you home with `G28`. Until the dock positions are calibrated (`docks_calibrated: False` in `indx.cfg`), G28 will not fetch T0 from its dock, because the dock positions in a new `indx.cfg` are placeholders. Z now probes with the load cell.

### Dock Position Calibration

Before any tool changes can happen, you need to find and save the exact dock position for each tool. Two coordinates are required per tool, both set in `indx.cfg`:

> 💡 **Dock calibration tool:** A printable jig ([`INDX_Dock_calibration_tool.stl`](CAD/STL/INDX_Dock_calibration_tool.stl)) is available to help align the dock during this process. Print it before starting.

| Variable | Meaning |
| --- | --- |
| `variable_t{n}_x` | X coordinate of the tool holder centre (mm) |
| `variable_t{n}_dock_y` | Y coordinate where the tool is fully seated (mm) |
| `variable_dock_dir` | Y sign into the dock: `-1` front (min Y), `+1` rear (max Y). Default `-1`. |

The trigger line (`dock_y - dock_dir * trigger_offset`) is derived automatically; you only set `dock_y`.

For a rear dock, set `variable_dock_dir: 1` and put `clearance_y` on the bed side of the tools.

`clearance_y` must be at least 26 mm from the most protruding dock, on the side away from the docks (a tool on the head needs 25 mm, plus 1 mm margin). With front docks that means the highest `t{n}_dock_y` + 26 or more; the default 0.0 fits the default docks at -26. G28, `CHANGE_TOOL` and `PARK_TOOL` refuse to run otherwise and name the dock. Check it again after re-measuring a dock.

> ⚠️ **Take this slow.** Moving the Smart Head into the dock area without verified coordinates is one of the most crash-prone steps in the entire INDX setup. A misaligned approach at speed can damage the Smart Head, the passive tools, or the dock itself.
>
> - **Always use the smallest jog increments available** (0.1 mm or less) when approaching a tool
> - **Never jog in Y toward the dock** until you are confident the X position is correct
> - **Keep your hand near the emergency stop** (or have it open in your browser) throughout this process
> - If anything looks wrong, stop immediately and re-evaluate before continuing

---

#### Finding dock_y (Y: fully seated position)

Put the tool on the Smart Head by hand and run `MANUAL_TOOL_SEAT TOOL=n` (tool changes are refused until `docks_calibrated` is True). With the Smart Head holding the tool, carefully jog in Y in small increments until the tool is fully seated in the dock. When it feels fully engaged, run:

```gcode
CAL_SET_DOCK_Y
```

The console will report the correct `dock_y` value for that tool, calculated from your current Y position and the configured `trigger_offset`. Paste the reported value into `indx.cfg`:

```ini
variable_t0_dock_y: -26.0   # from CAL_SET_DOCK_Y output
```

Repeat for each tool and restart Klipper to apply.

---

#### Finding dock_x (X: tool centre)

Three options; choose one:

**Option A: `CALIBRATE_DOCK_X` (automated, built in)**

Measures the absolute X position without needing a prior home, using the plugin's native `INDX_DOCK_MEASURE` (which derives the dock position from the raw stepper counts across the Y+X homing sequence).

1. `M84` (disable motors)
2. Manually slide the toolhead to the T0 dock
3. Run:
   ```gcode
   CALIBRATE_DOCK_X TOOL=0
   ```
   The macro homes Y then X and reports the measured `dock_x` for that tool. Paste it into `indx.cfg`:
   ```ini
   variable_t0_x: 0.000   # from CALIBRATE_DOCK_X output
   ```
4. For each additional tool: `M84`, slide to the dock, run `CALIBRATE_DOCK_X TOOL=N`. No `FIRMWARE_RESTART` needed between tools.
5. Once all tools are recorded, `RESTART` to apply, then `G28` to restore normal machine coordinates. If `docks_calibrated` is still False, seat T0 by hand (`MANUAL_TOOL_SEAT TOOL=0`) before this `G28`, or set `docks_calibrated: True` first if every dock is now measured.

**Option B: `READ_DOCK_POSITION` (if already homed)**

If the printer is already homed, jog the Smart Head to the tool's dock X position in Mainsail or Fluidd and run:

```gcode
READ_DOCK_POSITION TOOL=0
```

Reports the current X as `dock_x` for that tool. Paste the value into `indx.cfg` (`variable_t{n}_x`) and `RESTART` to apply.

**Option C: manual**

Home the printer, jog the Smart Head to the dock X for each tool, and note the X coordinate shown in the interface. Enter it as `variable_t{n}_x` in `indx.cfg`.

> 💡 **Home regularly.** Stepper motors can lose steps if a crash or hard stop occurs, meaning the position shown in your interface may no longer match the actual toolhead position. Re-home your printer (`G28`) before recording any coordinates, and again after any crash or unexpected movement. If you suspect steps have been lost, discard any coordinates taken since the last home and start that tool's calibration over.

#### First tool change test

Once you have calibrated the dock position for at least one tool, do a controlled first pick-up to confirm it works before setting up the full multi-tool configuration.

First set `variable_docks_calibrated: True` in `indx.cfg` and `RESTART`. Until then INDX refuses tool changes and parking, so a dock position that was never measured can't be driven into.

> ⚠️ **Take this slow.** Use the smallest jog increments and keep your hand near the emergency stop throughout. If anything looks wrong, stop immediately.

1. Home the printer (`G28`)
2. Pick up the tool:
   ```gcode
   T0
   ```
3. Confirm the Smart Head locks onto the tool and the nozzle begins heating
4. Once at temperature, confirm the DX extruder can feed filament (optional: extrude a short amount manually)
5. Park the tool back in the dock:
   ```gcode
   PARK_TOOL
   ```
6. Confirm the tool deposits cleanly and the Smart Head returns to a safe position

If the pick-up or deposit fails, do not retry at speed. Go back to the dock position calibration steps above and recheck the coordinates for that tool.

---

### Tool Offsets

Each passive tool has a slightly different position relative to the Smart Head pickup point. Tool offsets must be calibrated so prints align correctly when switching tools. There are several ways to do this, ranging from free manual methods to precise hardware-assisted ones.

To start over, `RESET_TOOL_OFFSETS` zeroes the X/Y/Z offset of every tool. It prints the old values first, so you can copy them back from the console if needed. The global Z offset is left alone (`RESET_GLOBAL_Z` handles that).

---

### Method 1: Print and adjust (free, no extra hardware)

The simplest approach: print a multi-tool test pattern, measure any misalignment visually or with calipers, and adjust offsets in your config manually. Repeat until aligned.

This is the lowest-cost method but also the least precise and most time-consuming. It's a good starting point if you have no other hardware available. A well-regarded starting point is the [Offset XY Dual Extruder / IDEX Calibration print](https://www.printables.com/model/129617-offset-xy-dual-extruder-idex-calibration); print it with two tools, measure any X/Y misalignment with calipers, update the offsets in your config, and reprint until they align.

Because the test print uses two tools at a time, always use T0 as your reference tool and calibrate each additional tool against it separately: first print T0 + T1, then T0 + T2, then T0 + T3, and so on. Do not try to calibrate T1 against T2 directly; everything should be referenced back to T0.

**Precision:** Low–medium | **Cost:** Free

---

### Method 2: Nudge (automatic, requires small hardware)

[Nudge](https://github.com/zruncho3d/nudge) is a low-cost contact probe that automates X/Y/Z nozzle alignment. The nozzle physically touches the probe from multiple directions; software calculates exact offsets for each tool automatically.

Nudge is highly repeatable, typically below 0.003mm standard deviation over 10 samples, and can be permanently mounted inside a heated chamber. It's a popular choice in the tool changer community.

**Precision:** High | **Cost:** Low (probe hardware + printed parts)

---

### Method 3: Nozzle camera (most precise XY, higher cost)

A nozzle-mounted or fixed camera system (e.g. [Axiscope](https://github.com/nic335/Axiscope)) lets you visually align tools with sub-micron precision. Offsets are derived from image analysis rather than physical contact.

The INDX macro package includes a built-in camera calibration workflow (`CAL_ONE` → `CAL_TWO` → `CAL_THREE`) that automates the offset calculation once a camera is set up.

**Workflow:**

1. Pick up T0 and jog the nozzle tip to the centre of your camera crosshair. Run:
   ```gcode
   CAL_ONE_SET_CAMERA_REF
   ```
   This saves the current position as the reference point.

2. For each additional tool, run:
   ```gcode
   CAL_TWO_PREP_TOOL_CAL TOOL=1
   ```
   The macro picks up the tool and moves it to the camera position. Re-centre the nozzle in the crosshair using the jog controls, then run:
   ```gcode
   CAL_THREE_SAVE_XY_OFFSET
   ```
   The offset is calculated and saved automatically. Repeat for every additional tool.

Offsets are saved as `t{n}_offset_x` / `t{n}_offset_y` and applied immediately on the next tool pick-up.

**Precision:** Very high | **Cost:** Medium–high (camera hardware)

---

### Z offset calibration

Regardless of which XY method you use, Z offsets are set automatically using the load cell.

#### Z auto-calibration: CAL_Z

`CAL_Z` probes every tool with the load cell and sets all Z offsets in one automated run. T0's probe result establishes the global Z offset.

```gcode
CAL_Z
```

By default, calibration is performed cold, preserving the existing behaviour. To
measure offsets with every nozzle at the same temperature, pass a nozzle target and
an optional soak time:

```gcode
CAL_Z NOZZLE_TEMP=150 SOAK=10
```

Each tool is heated only after pickup, held at the target for the requested soak,
then measured. The heater is switched off before that tool is parked. The bed heater
is not controlled by `CAL_Z`.

Prerequisites:
- Printer homed (homes automatically if not)
- **No filament available to the extruder gears in any tool** — if filament is loaded, latch engage moves during pickup can spike load-cell readings and cause calibration to fail.
- When using `NOZZLE_TEMP`, make sure the nozzle tips are clean. Any softened filament on a nozzle can affect the load-cell measurement.

Per tool, the macro:
1. Picks up the tool
2. Pre-probes 3× at a per-tool debris-clearing spot to clean the nozzle tip
3. Runs a convergence loop at a clean spot: probes repeatedly until the 4-sample rolling variance is below 0.005 mm, fuzzing to a new position if it stalls
4. Takes a median of 5 final samples as the result
5. Parks the tool

T0's median result sets the global Z reference. All other tools' offsets are saved as `t{n}_offset_z` relative to T0. Run `CAL_CHECK_OFFSETS` to inspect the results.

---

### Recommended approach

| Need | Recommended method |
| ---- | --- |
| Z offset only | `CAL_Z` |
| XY + Z, no extra hardware | Method 1 (print and adjust) or Method 2 (Nudge) for XY + `CAL_Z` for Z |
| Maximum XY precision | Method 3 (camera) for XY + `CAL_Z` for Z |

### Temperature & Induction Settings

Temperature is set in your slicer, the same way you would set it for any standard hotend: assign a target temperature to each filament or color in your project. INDX behaves like a normal hotend from the slicer's perspective.

The main difference from a traditional hotend is heat-up speed. A conventional heater block takes 30–60 seconds to reach printing temperature. With induction heating acting directly on the nozzle with very low thermal mass, INDX does it in around 4 seconds. That's what makes ~14-second tool changes possible.

**No induction-specific settings are required.** The induction board handles heating automatically. There are no power or frequency parameters to configure.

**Preheating is not supported and not possible.** Passive tools contain no electronics; there is nothing to preheat while a tool is parked in the dock. Do not configure standby or preheat temperatures for individual tools in your slicer; doing so may produce errors since the firmware has no way to act on them for a docked tool.

### Speed & Acceleration

Tool change motion speed and acceleration are controlled by three preset modes: **Stealth**, **Normal**, and **Sport**. Each mode sets a multiplier that is applied against the `max_velocity` and `max_accel` values defined in your `printer.cfg`. The macros read those limits at runtime, so the modes automatically scale to whatever printer they're running on, with no hardcoded numbers.

| Mode | G-code | Speed multiplier | Accel multiplier | XY stepper mode |
|---|---|---|---|---|
| **Stealth** | `MODE_STEALTH` | 20% | 20% | StealthChop (quiet) |
| **Normal** | `MODE_NORMAL` | 70% | 70% | SpreadCycle |
| **Sport** | `MODE_SPORT` | 100% | 100% | SpreadCycle |

**Stealth** runs the toolchange at 20% of your printer's configured limits. The XY steppers are switched to StealthChop, making the swap nearly silent. Useful for overnight printing or noise-sensitive environments. The trade-off is a longer toolchange duration and slightly higher stepper heat.

**Normal** is the default. It uses 70% of your printer's limits with SpreadCycle, a good balance of speed, noise, and reliability for most printers and materials.

**Sport** uses the full `max_velocity` and `max_accel` from your `printer.cfg`. This gives the fastest possible toolchange times for your specific printer. Make sure your configured limits are within what your printer can actually handle; if `max_velocity` or `max_accel` are set too high, Sport mode will expose that immediately. Input shaper should be tuned before running Sport; without it, high-acceleration toolchange moves can cause the steppers to lose steps.

Mode switching also sets StealthChop or SpreadCycle on every configured XY TMC driver (`tmc2208`, `tmc2209`, `tmc2130`, `tmc2240`, or `tmc5160`). On AWD setups, that includes `stepper_x1` and `stepper_y1` when present. Each driver is read from your `printer.cfg` individually, so mixed driver setups are handled correctly. If none of your XY steppers use a supported driver, the mode still changes speed and acceleration and INDX reports that the chopper mode was left untouched.

The active mode persists across reboots. To change it, run the macro from the console or add it to your start G-code:

```gcode
MODE_STEALTH   ; quiet/slow
MODE_NORMAL    ; default
MODE_SPORT     ; full speed
```

> **Note:** The speed limits are applied only during toolchange motion. As soon as the swap completes, the macros restore whatever velocity and acceleration limits the slicer set before the toolchange, and your print resumes at its normal print speeds.

---

**Part 4: Day-to-day Use**

---

## Using INDX

### Loading Filament into Tools

Filament can be loaded into a passive tool in three ways; try each and use what works best for your setup:

- **While the tool is in the dock**: convenient if the dock is easily accessible
- **While the tool is picked up by the Smart Head**: useful if the toolhead position is easier to reach
- **Before placing the tool in the dock**: load it on the bench, then dock it

There is no single correct method. Your printer geometry, spool placement, and personal preference will determine what works best.

**Guided loading with `LOAD_FILAMENT`**

The `LOAD_FILAMENT` macro handles the whole sequence for you: it picks up the tool, tells the safety thermal model which filament is loaded, heats to temperature, then feeds and primes.

```gcode
LOAD_FILAMENT TOOL=0 TYPE=PLA
```

- **`TOOL=<n>`** — which tool to load (it is picked up automatically).
- **`TYPE=<material>`** — applies a density + heat-capacity preset and a default load temperature. Built-in types: `PLA`, `PETG`, `ABS`, `ASA`, `PA`, `PC`, `TPU`. Edit the `filament_presets` table in `indx-cal.cfg` to add materials or tune values. Presets may also set an optional `speed` (mm/s) for the feed/prime step; `TPU` uses 2 mm/s so soft filament does not buckle during guided load.
- **`TEMP=<°C>`** *(optional)* — override the preset load temperature.
- **`MEASURE=1`** *(optional)* — measure this filament's actual heat capacity while loading instead of using the preset (most accurate). Run `SAVE_CONFIG` afterwards to keep it.

`LOAD_FILAMENT` needs a calibrated thermal model — run `INDX_CALIBRATE` first (see [First heat-up & heater calibration](#5-first-heat-up--heater-calibration)). The manual methods below work too; if you load by hand, set the filament's heat capacity separately so the safety model stays accurate.

**Filament path**

How filament is routed from the spool to the tool depends entirely on your printer. Common approaches include Bowden tubes from a spool holder to the dock, or direct-feeding from a nearby spool. There are no INDX-specific constraints on tube length for standard materials; route it in whatever way suits your printer.

**PTFE tube management**

With four or more tools, PTFE tube management becomes important. Loose, unrestrained tubes will move during printing and can knock into each other or into docked tools, potentially dislodging a tool from the dock mid-print, which can cause serious damage to the Smart Head, the tool, or the dock itself.

Two approaches work well:

- **Clip the tubes together**: bundle the PTFE tubes and clip them at intervals so they move as a single unit rather than independently
- **Mount the tubes rigidly along the top interior of the printer**: routing and securing the tubes along the frame keeps them stable and out of the motion path entirely. When doing this, make sure the tubes are long enough to reach all corners of the build area without pulling on the toolhead; a tube that is too short will create tension on the Smart Head as it moves, which can affect print quality or cause tool change failures

Either approach significantly reduces the risk of tubes interfering with docked tools. If you are running four or more tools, do not leave PTFE tubes unmanaged.

**Flexible filaments (TPU and similar)**

Keep the filament path as short as possible. Long Bowden paths cause flex filament to buckle rather than feed. Where possible, feed directly into the tool without a Bowden tube, or use a very short, straight tube. Avoid sharp bends in the path. `LOAD_FILAMENT TYPE=TPU` also feeds slower than other presets (2 mm/s); tune `speed` in `filament_presets` if needed.

### Performing Tool Changes

Tool changes happen automatically when triggered by your slicer's multi-material G-code. The Klipper plugin provides standard `T0`, `T1`, `T2` (etc.) macros for selecting any tool, the same commands your slicer will output.

You can also trigger a manual tool change directly from the Klipper console or a macro:

```gcode
T0  ; pick up tool 0
T1  ; pick up tool 1
T2  ; pick up tool 2
```

Mainsail and Fluidd show these macros as tool buttons and mark the tool INDX has on the head. If you have more tools than `T0` to `T3`, add `variable_active: False` to each extra `T<n>` macro in `indx.cfg`, like the four that ship with it. A `T<n>` macro without that line still changes tools but does not show as active.

> ⚠️ **Never remove a tool while the nozzle is heating.** If a tool is physically removed from the Smart Head while the induction coil is active, the firmware on the Bondtech INDX PCB will crash. You will need to run `FIRMWARE_RESTART` in the Klipper console before the printer can be used again.

**Priming before a print**

It is recommended to prime each nozzle before starting a print. Priming builds pressure in the nozzle and purges any filament that has been sitting idle and may have degraded or partially retracted. How you do this is up to you; common approaches include:

- A purge line in your slicer's print start G-code
- A prime routine in your `PRINT_START` macro
- A dedicated prime tower at the start of the print

The specifics depend on your slicer and macro setup. Check what other tool changer users in the community are doing for inspiration.

### Slicer Setup

Any slicer that supports **multiple filaments or colors** works with INDX; slicer compatibility is not INDX-specific. If your slicer can output multi-tool G-code (`T0`, `T1`, `T2`…), INDX can execute it.

Common slicers used with INDX include PrusaSlicer, OrcaSlicer, SuperSlicer, and Cura. Refer to your slicer's documentation for how to configure multiple extruders/tools.

**INDX-specific slicer settings to be aware of:**

- **Wipe tower:** A wipe tower is recommended for best results but not strictly required. Because INDX produces near-zero ooze by design, the wipe tower can be kept small compared to filament-switcher systems. You can experiment with disabling it for single-material-per-layer prints, but use it when printing materials prone to stringing.
- **Tool change G-code:** A small custom G-code snippet is required in your slicer's tool change script. The snippet and where to add it differs per slicer:

  **OrcaSlicer**

  Add under Printer Settings → Machine G-code → Change filament G-code:
  ```gcode
  CHANGE_TOOL TOOL={next_extruder} TEMP={new_filament_temp}
  M400
  ```

  `TEMP=` tells the toolchange what the incoming tool should heat to. Without it the macro can only fall back to the outgoing tool's temperature, which is correct when both tools print at the same temperature and wrong when they don't: the new tool gets brought to the old filament's temperature and only corrected afterwards. Passing it heats each tool to its own temperature once, with no overshoot and no second wait.

  `new_filament_temp` is a plain value OrcaSlicer computes for the incoming filament rather than an array you index yourself, and it is first-layer aware: the first layer temperature on layer one, the other-layers temperature after that. Earlier versions of this README used `nozzle_temperature[next_extruder]`. Either form works for an ordinary toolchange, but the scalar is harder to get wrong.

  > ⚠️ **If your toolchanges heat to the filament's maximum temperature**, the snippet is not the cause and changing it will not help. Check **Enable tower interface features** in Print Settings. When it is on, OrcaSlicer deliberately overrides the incoming filament's temperature on prime tower interface layers, where two materials meet, to that filament's **Interface layer print temperature**. That setting defaults to `-1`, and OrcaSlicer's own tooltip for it reads "If set to -1, use max recommended nozzle temperature". So every interface-layer toolchange heats to the filament's max, by design.
  >
  > Fix it at the source: either give **Interface layer print temperature** a real value on each filament, or turn **Enable tower interface features** back off. It is off by default, so if you have not touched it this does not apply to you. The override is applied after the placeholder is filled in, so no change to the G-code above can avoid it.

  **PrusaSlicer / SuperSlicer**

  1. Under Printer Settings → General → Capabilities, set **Number of extruders** to match your tool count
  2. Make sure **Single Extruder Multimaterial Printer** is **unchecked**; this mode is for filament switchers (MMU/AMS) and must be off for a tool changer
  3. Under Printer Settings → Custom G-code → Tool change G-code, add:
  ```gcode
  T{next_extruder}
  {if (wipe_tower)}
  G0 Y{wipe_tower_y+2} X{wipe_tower_x+2} F{travel_speed*60}
  G0 Z{layer_z} F{travel_speed*60}
  {endif}
  M104 S{temperature[next_extruder]}
  TEMPERATURE_WAIT SENSOR=extruder MINIMUM={temperature[next_extruder]-5} MAXIMUM={temperature[next_extruder]+5}
  ```

  This selects the next tool, moves to the wipe tower (if one is enabled) so the new (initially cold) tool heats and purges there, then sets the new tool's temperature and waits for the induction coil to bring it up to temperature before printing resumes.

  This snippet works as written and needs no changes. If your tools print at different temperatures you can optionally replace the `T{next_extruder}` line with the form below, which heats the new tool straight to its own temperature instead of reaching the old tool's first and correcting afterwards:

  ```gcode
  CHANGE_TOOL TOOL={next_extruder} TEMP={temperature[next_extruder]}
  ```

  Keep the `M104` and `TEMPERATURE_WAIT` lines either way; they cost nothing once the temperature is already correct.

  **SuperSlicer** uses the same template engine and variable names as PrusaSlicer, so this snippet works unchanged in both. (PrusaSlicer's older `[...]` placeholder form also works in both if you prefer it, e.g. `M104 S[temperature[next_extruder]]`.)

  **Cura**

  > ⚠️ This configuration has not been fully verified. If you run into issues, ask on the [Bondtech Discord](https://discord.gg/XDX9jDXN6e).

  Cura handles tool changes differently from the PrusaSlicer family: it emits the `T{n}` command automatically and runs **per-extruder** start/end G-code, so there is no single "tool change G-code" field to edit. Configure it as follows:

  1. In **Settings → Printer → Manage Printers → Machine Settings**, set **Number of Extruders** to match your tool count. Cura then outputs `T0`, `T1`, … automatically at each tool change.
  2. Enable **Prime Tower** (search "prime tower" in the print settings). This is Cura's equivalent of the wipe tower; Cura moves to it and purges the freshly heated tool automatically, so you don't script the move yourself.
  3. In **Machine Settings**, open each extruder's tab and add to its **Extruder Start G-code** (this runs every time that tool becomes active):
  ```gcode
  M104 S{material_print_temperature}
  TEMPERATURE_WAIT SENSOR=extruder MINIMUM={material_print_temperature}
  ```

  > **Notes for Cura:**
  > - Cura's start/end G-code does **not** support arithmetic in placeholders (e.g. `{material_print_temperature - 5}` will not work), so use the bare target. Because an INDX tool is always cold when picked up, waiting on `MINIMUM` alone is sufficient; the nozzle only ever needs to heat *up* to temperature.
  > - Do **not** set per-extruder **Standby Temperature** values; passive tools cannot be preheated in the dock (see [Temperature & Induction Settings](#temperature--induction-settings)).
- **Slicer profiles:** Pre-made printer profiles for INDX are being developed and will be made available before release. They are not ready for general use yet.

---

**Part 5: Designing for INDX**

---

## Designing for INDX

This section is for users who want to design custom mounts, docks, or printer integrations for INDX.

### Dock Design

The dock holds passive tools in precise, repeatable positions so the Smart Head can pick them up reliably. There are strict geometry requirements; a dock that doesn't meet them will cause failed or inconsistent tool changes.

The reference dock design is available on [github.com/BondtechAB/INDX](https://github.com/BondtechAB/INDX). Use it as the starting point for any custom design.

**Key design constraints**

Each dock is approximately **70mm tall, 28.5mm wide (X), and 25mm deep (Y)**. Minimum tool center-to-center spacing is **34mm** bare, or **41mm** when using the Bondtech part cooling solutions. The design must achieve a pickup repeatability of **within 0.2mm**.

**Material recommendations**

Bondtech's sold docks use SLS-printed Nylon 12 GF. For self-printed docks, use a material that is dimensionally stable at elevated temperatures; the dock sits near the print area and will experience heat cycles. ASA or ABS are common choices. Avoid PLA.

**Community designs**

Community dock designs for specific printers and frames are collected in [`community/`](community/). The [2020 extrusion dock](community/1_printer_agnostic/2020-dock/) there is a good worked example of adapting the reference geometry: it keeps the same hardware and the same dimensions on every other axis, and only the body changed. If you design a dock for an unlisted setup, submit it via pull request.

### Part Cooling

INDX's modular part cooling system is designed to be extended by the community. The cooling solution snaps onto the outside of the Smart Head cowlings, and the interface geometry is published, so you have everything you need to design against it.

What a shroud actually attaches to is the fan shroud clip, [`INDX_Part_Cooling_Interface_left.stl`](CAD/STL/INDX_Part_Cooling_Interface_left.stl) and [`INDX_Part_Cooling_Interface_right.stl`](CAD/STL/INDX_Part_Cooling_Interface_right.stl). The cowlings those clip to are [`INDX_Front_cover_left.stl`](CAD/STL/INDX_Front_cover_left.stl) and [`INDX_Front_cover_right.stl`](CAD/STL/INDX_Front_cover_right.stl). All of it is in the reference STEP model as well, which is the better starting point for CAD work. See [CAD Files & Templates](#cad-files--templates).

Bondtech's own ducts are in the repository too and are worth reading as worked examples of the same interface: the dual 40×10 blower ducts and the CPAP ducts, including its top manifold.

Two constraints to design within. Minimum tool centre-to-centre spacing goes from 34 mm bare to **41 mm** with the Bondtech cooling solutions fitted, so anything wider than those eats into dock spacing. And the tools cool passively while docked, so a shroud that blocks airflow around a parked tool works against the system rather than with it.

If you design a custom part cooling solution, we'd love to see it. Community-contributed cooling designs are welcome in [`community/`](community/); submit yours via pull request.

### CAD Files & Templates

All official CAD files are hosted on **Bondtech's GitHub**: [github.com/BondtechAB/INDX](https://github.com/BondtechAB/INDX)

**Reference geometry (STEP)**

The STEP file is the master reference model; it contains the geometry of every printable part listed below, so use it as the starting point for designing custom mounts, adapters, or cooling solutions.

| File | Format | Description |
| ---- | --- | --- |
| [`INDX_simplified_1.19.step`](CAD/INDX_simplified_1.19.step) | STEP | Simplified reference model of the full INDX assembly. Includes the open nozzle front, so you can modify it and print your own |
| [`INDX_Link_simplified_1.0.step`](CAD/INDX_Link_simplified_1.0.step) | STEP | Simplified reference model of the Link Board, for designing a mount or enclosure for it |

**Printable parts (STL)**

These are print-ready STLs of the individual parts. They are all derived from the reference STEP above.

**Which Tool Dock body to print.** The dock body comes in two variants because the two 15×15 profiles do not take the same fastener: MakerBeam XL has an indexing track running down the slot that a standard 1515 T-nut will not clear.

Print the **standard extrusion** body unless you have a reason not to. It suits both standard 1515 and MakerBeam XL, so it is the easier all-round choice and it keeps the dock usable if you ever move it to a different frame. The **MakerBeam XL** body is the original, and it is the geometry Bondtech's ready-made docks use; it mounts on standard 1515 as well, given a fastener that suits. Print one or the other, not both. The spring lid and magnet holder are the same either way.

See [Mount the Dock](#2-mount-the-dock) for what the dock mounts to.

| File | Part | Description |
| ---- | ---- | --- |
| [`INDX_MGN12H_X-carriage.stl`](CAD/STL/INDX_MGN12H_X-carriage.stl) | X-carriage adapter | Mounts the Smart Head to MGN12H linear rails (6mm belts) |
| [`INDX_Front_cover_left.stl`](CAD/STL/INDX_Front_cover_left.stl) | Smart Head cover | Front cover, left half |
| [`INDX_Front_cover_right.stl`](CAD/STL/INDX_Front_cover_right.stl) | Smart Head cover | Front cover, right half |
| [`INDX_PCB_Cover.stl`](CAD/STL/INDX_PCB_Cover.stl) | PCB cover | Protective cover for the Bondtech INDX PCB |
| [`INDX_Part_Cooling_Interface_left.stl`](CAD/STL/INDX_Part_Cooling_Interface_left.stl) | Part cooling mount | Fan shroud clip, left. Attaches a fan shroud to the left Front Cover; see [Install the Smart Head](#1-install-the-smart-head) |
| [`INDX_Part_Cooling_Interface_right.stl`](CAD/STL/INDX_Part_Cooling_Interface_right.stl) | Part cooling mount | Fan shroud clip, right. Attaches a fan shroud to the right Front Cover |
| [`INDX_4010_Duct_Left.stl`](CAD/STL/INDX_4010_Duct_Left.stl) | Part cooling (4010) | Dual 40×10 blower duct, left half |
| [`INDX_4010_Duct_Right.stl`](CAD/STL/INDX_4010_Duct_Right.stl) | Part cooling (4010) | Dual 40×10 blower duct, right half |
| [`INDX_CPAP_Duct_Left.stl`](CAD/STL/INDX_CPAP_Duct_Left.stl) | Part cooling (CPAP) | CPAP duct, left half |
| [`INDX_CPAP_Duct_Right.stl`](CAD/STL/INDX_CPAP_Duct_Right.stl) | Part cooling (CPAP) | CPAP duct, right half |
| [`INDX_CPAP_Duct_Top.stl`](CAD/STL/INDX_CPAP_Duct_Top.stl) | Part cooling (CPAP) | CPAP duct, top manifold |
| [`INDX_Beacon_Cartographer_Mount.stl`](CAD/STL/INDX_Beacon_Cartographer_Mount.stl) | Probe mount | Mount for a Beacon / Cartographer scanning probe |
| [`INDX Tool Dock 1515 Standard extrusion.stl`](CAD/STL/INDX%20Tool%20Dock%201515%20Standard%20extrusion.stl) | Tool Dock body | Dock main body, one per dock. Suits standard 1515 **and** MakerBeam XL; print this one unless you have a reason not to |
| [`INDX Tool Dock 1515 MakerbeamXL.stl`](CAD/STL/INDX%20Tool%20Dock%201515%20MakerbeamXL.stl) | Tool Dock body | Dock main body, one per dock. Matches Bondtech's ready-made docks. Mounts on standard 1515 too; see the fastener note in [Mount the Dock](#2-mount-the-dock) |
| [`INDX Tool Dock 1515 Spring lid.stl`](CAD/STL/INDX%20Tool%20Dock%201515%20Spring%20lid.stl) | Tool Dock part | Spring lid, common to both dock bodies |
| [`INDX Tool Dock 1515 Magnet holder.STL`](CAD/STL/INDX%20Tool%20Dock%201515%20Magnet%20holder.STL) | Tool Dock part | Magnet holder slider, common to both dock bodies |
| [`INDX_Dock_calibration_tool.stl`](CAD/STL/INDX_Dock_calibration_tool.stl) | Dock calibration tool | Printed jig for calibrating dock position during initial setup; see [Dock Position Calibration](#dock-position-calibration) |

The repository is licensed under **GPL-3.0**.

More files (additional X-carriage adapters, tool body templates) will be added as the project develops. Community contributions are welcome via pull request.

---

**Part 6: Maintenance, Support & Community**

---
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

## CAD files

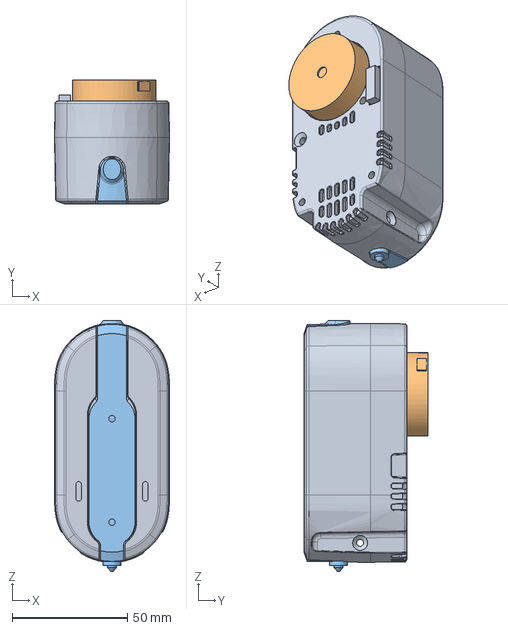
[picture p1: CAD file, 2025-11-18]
CAD/INDX_simplified_1.0.step
50.0 x 53.9 x 109.1 mm
TC3 PRINTHEAD REAR PART
TC3 NOZZLE ASSEMBLY

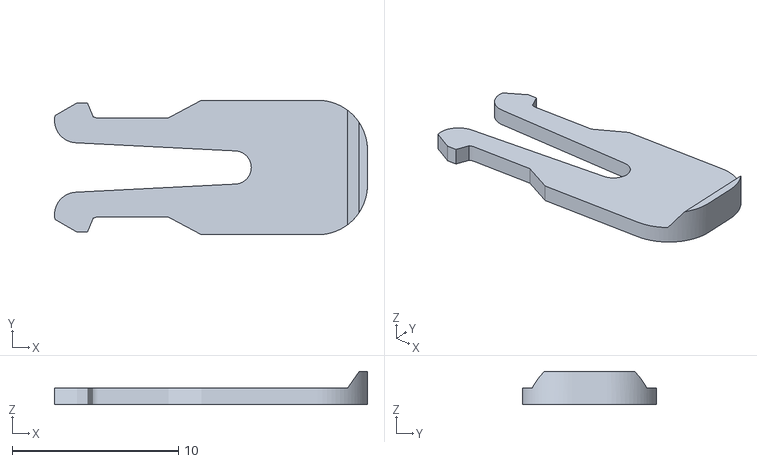
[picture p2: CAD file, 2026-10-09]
CAD/STL/INDX Tool Dock 1515 Spring lid.stl
18.9 x 8.10 x 2.00

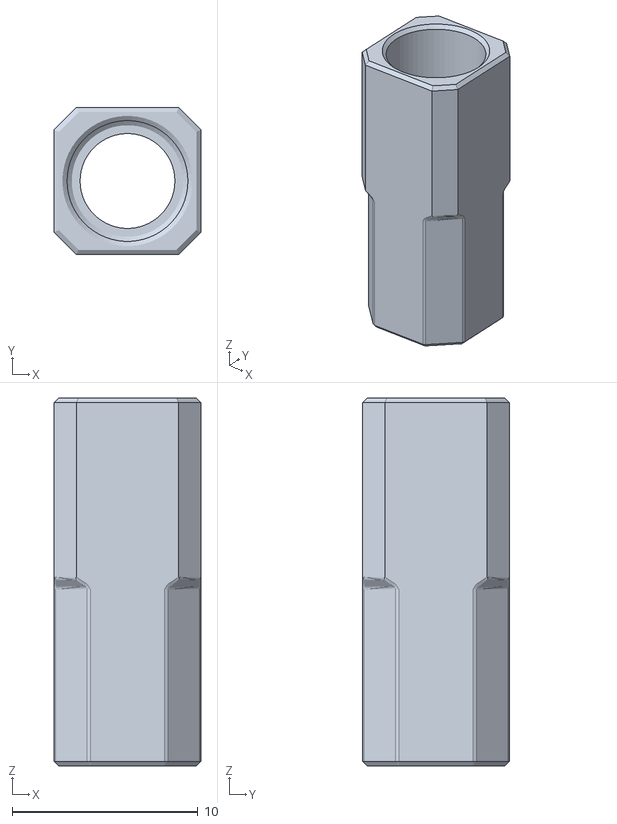
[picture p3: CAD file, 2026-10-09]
community/1_printer_agnostic/2020-dock/[a]_magnet_holder_1x.stl
7.90 x 7.90 x 19.8

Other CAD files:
community/1_printer_agnostic/2020-dock/[a]_spring_lid_1x.stl

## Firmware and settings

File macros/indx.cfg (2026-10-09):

#####################################################################
#  INDX USER CONFIGURATION
#####################################################################
#
#  This is the ONLY file you need to edit to adapt INDX to your
#  machine. All other INDX config files derive their values from
#  the variables defined here.
#
#  HOW TO CONFIGURE TOOLS:
#    Set tool_count to the number of tools installed.
#    Then fill in one pair of variables per tool (tN_x, tN_dock_y).
#       x      — X coordinate centred on the tool holder (mm)
#       dock_y — Y coordinate where the tool is fully seated (mm)
#                (deeper into the dock along dock_dir)
#
#    Tool number = variable suffix.  t0 = T0, t1 = T1, etc.
#    Add or remove pairs and update tool_count — the system adapts automatically.
#
#  WHAT IS AUTO-DERIVED:
#    - Trigger Y per tool (dock_y - dock_dir * trigger_offset)
#
#  WHAT NOT TO TOUCH:
#    - E-axis moves and dance geometry are fixed hardware constants
#      defined in indx-tc-macros.cfg. These are determined by the
#      INDX mechanism and must not be changed.
#
#####################################################################

[gcode_macro TOOL_POSITIONS]
description: INDX tool positions (user-configurable)

# ── How many tools are installed ─────────────────────────────────────────────
variable_tool_count: 3

# ── Z-hop during toolchange ──────────────────────────────────────────────────
#  z_hop = distance (mm) to raise Z before the toolhead travels to the dock.
#          Z clears first and lands before any XY movement starts, and on the
#          way back Z only drops once XY has reached the clearance line. Those
#          are separate moves on purpose: running Z and XY together raises or
#          lowers the nozzle gradually across the travel, which drags it over
#          the print at both ends of the change.
#          Set to 0.0 to disable.
variable_z_hop: 1.0

# ── Z offset auto-calibration probe position ─────────────────────────────────
#  Used by CAL_Z_AUTO_ALL to probe each tool and calibrate Z offsets.
#
#  probe_x / probe_y  — centre of the probing area (machine coords, mm).
#                       Set to the centre of your bed. The macro will probe
#                       here for debris clearing, then +5 mm in X for the
#                       actual measurement.
#  probe_fuzz         — legacy fuzz radius, kept for compatibility (mm).
#  probe_z_clearance  — Z height (gcode space) the toolhead travels to before
#                       descending to probe. Must clear any bed features.
variable_probe_x:          -1.0   # set to bed centre X, or -1 to auto-detect
variable_probe_y:          -1.0   # set to bed centre Y, or -1 to auto-detect
variable_probe_fuzz:         2.0
variable_probe_z_clearance: 10.0

# ── Homing move speeds ───────────────────────────────────────────────
#  These cover only the moves the homing override makes itself: the step
#  aside to clearance_y before X is homed, the Z hop, the travel to the
#  probe point, and the lift afterwards.
#
#  The homing passes themselves are plain G28 X / G28 Y / G28 Z, so Klipper
#  applies whatever homing_speed, second_homing_speed, homing_retract_dist
#  and homing_positive_dir are set on your steppers. Nothing here overrides
#  those, and they do not need repeating.
#
#  home_travel_feedrate = mm/min for the XY moves listed above.
#  home_z_feedrate      = mm/min for the Z hop and the post-probe lift.
#                         Lower this for a slow leadscrew.
variable_home_travel_feedrate: 3000
variable_home_z_feedrate:       900

# ── Homing seat check ────────────────────────────────────────────────────────
#  home_check_seat = ask the load cell whether a tool is seated before G28 Z.
#                    Opt-in, and off by default.
#
#                    The load cell is a reliable contact detector, which is what
#                    probing needs, and an unreliable scale, which is what this
#                    check needs. Its absolute reading in grams moves with the
#                    tare, and a head tared with a tool already in it reads near
#                    zero with that tool still seated. Turning this on means a
#                    bad reading can refuse a homing that would have been fine.
#                    Leaving it off means INDX trusts active_tool instead, which
#                    is what every other tool-change operation already trusts.
#
#                    Either way the load cell is still the Z probe. This setting
#                    only decides whether its absolute reading gates homing.
#
#                    Write True or False, capitalised: Klipper parses these as
#                    Python literals and a lower-case true is a startup error.
variable_home_check_seat: False

#  home_min_force_g = grams the load cell must show before G28 Z.
#                     Only used when home_check_seat is True.
#                     Empty head sits well below this.
#                     Raise if an empty head is accepted as seated;
#                     lower only if a seated tool is refused.
variable_home_min_force_g: 800.0

# ── Pickup and park checks ───────────────────────────────────────────────────
#  seat_check_enabled = check every pickup and every park with the load cell.
#                       On by default. Each check compares two readings taken
#                       standing still seconds apart, so the tare and the
#                       load cell's drift do not matter, unlike home_check_seat.
#                       With no calibrated load cell the checks are skipped
#                       with one console line. Set False to turn them off.
#                       Write True or False, capitalised.
#
#                       Pickup: the reading after the pickup must differ from
#                       the empty head before it by seat_min_force_g. If not,
#                       X/Y is re-homed and the tool picked up once more. If
#                       that fails too, a print pauses and anything else stops,
#                       with the heater off and no tool recorded. A reading
#                       between seat_empty_max_g and seat_min_force_g means
#                       something may be half seated on the head: no retry,
#                       the tool stays recorded, and it pauses or stops. G28 Z,
#                       CHANGE_TOOL and PARK_TOOL then refuse, also after a
#                       restart, until the head is checked by hand and
#                       MANUAL_TOOL_REMOVE or MANUAL_TOOL_SEAT TOOL=<n> is run.
#
#                       Park: the reading after the drop-off must differ from
#                       the seated one by park_min_change_g. If not, the tool
#                       is still on the head: INDX stops with the heater off
#                       and keeps the tool recorded as on the head.
variable_seat_check_enabled: True

#  seat_min_force_g  = grams a seated tool must show against the empty head.
#                      Seated tools show 1100 to 1900 g on the test machine.
#  seat_empty_max_g  = below this a failed pickup counts as an empty head.
#                      From here up to seat_min_force_g it counts as a tool
#                      that may be half seated, and INDX keeps it recorded.
#  park_min_change_g = grams the reading must change by when a tool is parked.
variable_seat_min_force_g: 680.0
variable_seat_empty_max_g: 230.0
variable_park_min_change_g: 425.0

# ── Dock approach direction ──────────────────────────────────────────────────
#  dock_dir = Y sign into the dock: -1 front (min Y), +1 rear (max Y).
#             Flips trigger line, unlock depths, peel, and the homing
#             X-clearance check relative to dock_y.
variable_dock_dir: -1

# ── Trigger offset ───────────────────────────────────────────────────────────
#  trigger_offset = distance (mm) from dock_y to the trigger line.
#                   trigger_y is auto-derived as: dock_y - dock_dir * trigger_offset
#                   Increase if the latch engages before the tool is fully seated;
#                   decrease if the toolhead overshoots the dock.
variable_trigger_offset: 5.0

# ── Safe lateral travel position ─────────────────────────────────────────────
#  clearance_y = Y coordinate where the toolhead clears ALL docked tools.
#                The toolhead moves here before any X travel between tools.
#                Set this to the Y position where no tool bodies are in the way.
#                It must be at least 26 mm from the most protruding dock
#                (a tool needs 25 mm, plus 1 mm margin), on the side away
#                from the docks (front docks: the highest tN_dock_y + 26 or
#                more). Homing and tool changes refuse to run otherwise.
variable_clearance_y: 0.0        # default docks at -26: -26 + 26
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

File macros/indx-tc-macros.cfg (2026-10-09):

#####################################################################
#  INDX HARDWARE CONSTANTS
#####################################################################
#
#  These values are fixed by the INDX mechanism geometry and gear
#  mesh. DO NOT MODIFY unless you are changing the physical hardware.
#
#  Per-tool positions are derived as:
#     trigger_y   = tool.dock_y - TOOL_POSITIONS.dock_dir * trigger_offset
#     clearance_y = TOOL_POSITIONS.clearance_y                   (set in indx.cfg)
#
#####################################################################

[gcode_macro _INDX_CONSTANTS]
description: Fixed INDX hardware constants — do not modify

# --- Dock geometry ---
# Distance for the gentle peel-off after parking/pickup (relative move)
variable_peel_distance: 10.0

# --- Unlock dance: Y depths toward the dock from trigger_y ---
# These define the waypoints of the wiggle sequence.
# Expressed as positive distances along dock_dir from trigger_y.
variable_squeeze_depth: 0.5
variable_wiggle_in_depth: 1.0
variable_wiggle_out_depth: 2.0

# --- Unlock dance: E-axis moves (gear mesh — do not change) ---
variable_squeeze_e: -0.27
variable_wiggle_in_e: 0.27
variable_wiggle_out_e: -1.7
variable_full_open_e: -11.0
variable_full_lock_e: 11.0

# --- Feed rates (mm/min) ---
variable_squeeze_feedrate: 2000
variable_wiggle_feedrate: 2500
variable_dock_feedrate: 3000
variable_latch_feedrate: 1500
variable_peel_feedrate: 3000
variable_engage_feedrate: 2500

# --- Extruder current (amps) ---
variable_squeeze_current: 0.2
variable_run_current: 0.6

# --- E-axis rotation distance for TC moves ---
# All E moves in the macros use this value regardless of what is set in printer.cfg.
# printer.cfg rotation_distance is restored after every macro that issues E moves.
variable_tc_rotation_distance: 5.7

gcode:

#####################################################################
#  1. GLOBAL VARIABLES & STATUS DASHBOARD
#####################################################################

[gcode_macro _TOOLCHANGE_VARS]
variable_mode: "normal"
variable_accel_mult: 0.7
variable_speed_mult: 0.7
variable_toolhead_state: 0 # 0=Locked, 2=Open
variable_rotation_dist_overridden: 0
# Set by [homing_override] so CHANGE_TOOL/PARK_TOOL do not re-enter G28 mid-home.
variable_homing_busy: 0
gcode:

[delayed_gcode INIT_STATE]
initial_duration: 5.0
gcode:
    _INDX_BUILD_TOOLS

    {% set svv = printer.save_variables.variables %}
    # Restore saved latch state so INDX displays the correct Open/Locked label after a
    # firmware restart. The INDX latch is mechanically self-retaining, so the saved value
    # accurately reflects the physical position across restarts.
    # Defaults to 0 (Locked) on first boot before any toolchange has been recorded.
    SET_GCODE_VARIABLE MACRO=_TOOLCHANGE_VARS VARIABLE=toolhead_state VALUE={svv.toolhead_state|default(0)|int}

    MODE_{svv.tc_mode|default("NORMAL")|upper}
    # Show the saved tool on the Mainsail/Fluidd tool buttons
    _INDX_SET_ACTIVE_TOOL TOOL={svv.active_tool|default(-1)|int}
    TOOL_STATUS

[gcode_macro _INDX_BUILD_TOOLS]
description: Inner - build TOOL_POSITIONS.tools from the numbered tN_x / tN_dock_y variables
# INIT_STATE runs it 5 s after a restart. G28, CHANGE_TOOL and PARK_TOOL run
# it first when the list is still empty, so a command in those first seconds
# does not fail half way (a G28 used to die in the T0 fetch with Z still
# marked homed at the hop height, PR #58). The macros that index the list
# render after this one has run.
gcode:
    {% set tp = printer["gcode_macro TOOL_POSITIONS"] %}
    {% set ns = namespace(json="") %}
    {% for i in range(tp.tool_count|int) %}
        {% set x  = tp["t" ~ i ~ "_x"]|float %}
        {% set dy = tp["t" ~ i ~ "_dock_y"]|float %}
        {% set entry = '{"x": %.3f, "dock_y": %.3f}' % (x, dy) %}
        {% if loop.first %}
            {% set ns.json = "[" ~ entry %}
        {% else %}
            {% set ns.json = ns.json ~ ", " ~ entry %}
        {% endif %}
    {% endfor %}
    SET_GCODE_VARIABLE MACRO=TOOL_POSITIONS VARIABLE=tools VALUE='{ns.json}]'

[gcode_macro _INDX_CHECK_CLEARANCE]
description: Inner - refuse to home or change tools if clearance_y is closer than min_dock_clearance to the most protruding dock
# A tool on the head needs 25 mm from the most protruding dock, on the side
# away from the docks; min_dock_clearance adds 1 mm margin. Every dock exit,
# the travel between docks and the X home run along clearance_y, so a line
# that is too close (for example after a dock re-measure) drives a tool on
# the head into the docked tools. Reads tN_dock_y directly, so it also works
# before INIT_STATE has built the tools list.
variable_min_dock_clearance: 26.0
gcode:
    {% set tp = printer["gcode_macro TOOL_POSITIONS"] %}
    {% set ns = namespace(gap=999.0, tool=-1) %}
    {% for i in range(tp.tool_count|int) %}
        {% set gap = (tp["t" ~ i ~ "_dock_y"]|float - tp.clearance_y|float) * tp.dock_dir|float %}
        {% if gap < ns.gap %}
            {% set ns.gap = gap %}
            {% set ns.tool = i %}
        {% endif %}
    {% endfor %}
    {% if ns.gap < min_dock_clearance|float - 0.001 %}
        _INDX_LCD LEVEL=warn MSG="clearance_y too close to T{ns.tool} dock"
        _INDX_RAISE MSG="{'INDX: clearance_y %.3f is only %.2f mm from the T%d dock (dock_y %.3f); it must be at least %.1f mm. Fix clearance_y in indx.cfg before any homing or tool change.' % (tp.clearance_y|float, ns.gap, ns.tool, tp['t' ~ ns.tool ~ '_dock_y']|float, min_dock_clearance|float)}"
    {% endif %}

[gcode_macro _INDX_LCD]
description: Show an INDX alert on the printer display (M117). LEVEL=warn: dangerous to ignore; LEVEL=action: you need to do something. Everything else stays in the console only
# The display line is short (about 40 characters); the console keeps the
# full explanation. An alert clears itself after the next successful G28
# (_INDX_LCD_CLEAR), and only if INDX put it there, so the slicer's own M117
# messages are left alone.
variable_shown: 0
gcode:
    {% set lvl = params.LEVEL|default("action")|lower %}
    M117 {"! " if lvl == "warn" else "> "}{params.MSG|default("INDX: see console")}
    SET_GCODE_VARIABLE MACRO=_INDX_LCD VARIABLE=shown VALUE=1

[gcode_macro _INDX_LCD_CLEAR]
description: Inner - clear the display line if it shows an INDX alert
gcode:
    {% if printer["gcode_macro _INDX_LCD"].shown|int %}
        M117
        SET_GCODE_VARIABLE MACRO=_INDX_LCD VARIABLE=shown VALUE=0
    {% endif %}

[gcode_macro _INDX_RAISE]
description: Inner - raise an error from its own macro, so the commands before it (heater off, messages) still run; inside G28 it first undoes the provisional Z home
# A raise inside G28 (for example a failed T0 pickup in the homing T0 fetch)
# must leave the machine as _INDX_HOME_Z_FAIL would: homing_busy cleared, and
# Z not homed if it was only marked homed at the hop height (z_faked).
# Otherwise Z reports homed at a made-up origin (PR #58 / #71).
# The raise itself is a separate macro: a template raises while it renders,
# before any of its own commands run.
gcode:
    {% if printer["gcode_macro _TOOLCHANGE_VARS"].homing_busy|default(0)|int %}
        SET_GCODE_VARIABLE MACRO=_TOOLCHANGE_VARS VARIABLE=homing_busy VALUE=0
        {% if printer["gcode_macro _INDX_HOME_Z"].z_faked|default(0)|int %}
            SET_KINEMATIC_POSITION SET_HOMED= CLEAR_HOMED=Z
            SET_GCODE_VARIABLE MACRO=_INDX_HOME_Z VARIABLE=z_faked VALUE=0
            RESPOND TYPE=error MSG="INDX: homing stopped, Z is not homed"
        {% endif %}
    {% endif %}
    _INDX_RAISE_NOW MSG="{params.MSG|default('INDX error')}"

[gcode_macro _INDX_RAISE_NOW]
description: Inner - raise the error (called by _INDX_RAISE)
gcode:
    { action_raise_error(params.MSG|default("INDX error")) }
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

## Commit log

2026-09-10 Fix XY offset save moving an aligned tool
    [indx-cal.cfg]
2026-09-11 Follow the camera macro rename through, and document the recovery macros
    The rename in #64 changed the three macro definitions but not the places
    that name them. Eight references in indx-cal.cfg and five in the README
    still pointed at CAL_01/02/03, including the prompt telling you what to run
    next, the usage error and the missing-reference error. Following the
    documented workflow would have kept failing for the original reason.
    MANUAL_TOOL_REMOVE and MANUAL_TOOLHEAD_RESET from #65 had no documentation
    anywhere. Added a troubleshooting entry covering when the saved tool state
    disagrees with reality, with the distinction between the two spelled out:
    one opens the latch and drops whatever is h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
    [indx-cal.cfg]
2026-09-11 Drop the snap-back description from the camera workflow comment
    The comment said step 3 snaps back to verify alignment, which described
    the MOVE=1 that #63 removed. The macro now deliberately leaves the nozzle
    where it is and shifts only the coordinate system, which is the whole point
    of that fix.
    [indx-cal.cfg]
2026-09-11 List the Voron 2.4 community parts set
    Adds karasgit/INDX-for-Voron-2.4 and Emplikac 000's walkthrough video
    against the Voron 2.4 row, which had no notes at all.
    Marked unverified, with a note above the table saying what that means:
    Bondtech has not printed, measured or run these parts, they are listed as a
    starting point rather than an endorsement, and questions about them go to
    whoever made them. The dock geometry in particular is worth checking against
    Dock Design before printing, since a dock that misses those constraints
    fails tool changes rather than failing obviously.
2026-09-11 Separate unverified community builds from printer compatibility
    Supported Printers had one table doing two jobs: answering whether INDX
    runs on a given printer, and pointing at parts someone has published for it.
    Those carry very different weight, and the unverified build link was buried
    in a Notes column next to rows that make no claim at all.
    Three sections now, strongest claim first. Officially recognized, then
    unverified builds with the warning attached to the table it describes, then
    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
2026-09-11 Collapse to two tables: recognized, and everything else
    Every printer now appears exactly once. The compatibility table is gone as a
    separate thing; printers with a recognized build are listed there, printers
    with an unverified build or none yet are in the second table.
    That removes the cross-references each table was making to the other, and
    the duplication where Voron Trident and Sovol appeared in both.
    Empty rows say what they mean. RatRig V-Core has nothing published yet.
    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
2026-09-15 Fix recursive macro error when homing Z with no tool seated
    Homing with an empty load cell aborted with "Macro _INDX_HOME_VERIFY called
    recursively" right after T0 was picked up. Klipper refuses to re-enter a
    gcode_macro that is still on the call stack, and the second seat check was
    doing exactly that: _INDX_HOME_VERIFY called _INDX_HOME_VERIFY_READ, which
    called _INDX_HOME_Z_AFTER_SOFT, which called _INDX_HOME_VERIFY again with
    NEXT=hard while the first one had not returned.
    The path with a tool already seated goes straight to the probe and never
    re-enters, which is why this only showed up when homing with no tool.
    The NEXT parameter and the next_hard variable are gone. The second check r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
    [homing.cfg]
2026-09-15 Lift to clearance after the Z probe
    G28 Z ends with the nozzle at the trigger point, which is a fraction of a
    millimetre off the bed. Anything that ran next started from there, so a bare
    G28 left the head parked against the surface and any XY move that followed
    dragged the nozzle across it.
    The probe now lifts to probe_z_clearance, the same height _INDX_SAFE_Z_HOP
    uses on the way in, so the sequence starts and ends at a known safe height.
    [homing.cfg]
2026-09-15 Do not park a phantom tool when homing with an empty cell
    Homing Z with an empty load cell picks T0 to get a probe, and cleared
    active_tool first only when the saved value was already 0, to stop CHANGE_TOOL
    short-circuiting on act != t.
    With any other saved tool that guard did not fire. CHANGE_TOOL then ran the
    full swap and parked the saved tool, driving to a dock with nothing in the
    gripper. Its Z-sync step also ran, folding the phantom tool's Z offset into
    global_z_offset, which is saved and read by every later tool change.
    The load cell is the authority. If it reads empty then active_tool is wrong
    whatever it says, so clear it unconditionally. CHANGE_TOOL skips both the park
    and the Z-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
    [homing.cfg]
2026-09-15 Clear the dock line before homing X, and say what the seat check read
    Three changes from a report of two crashes during G28 with a tool seated and
    active, refused afterwards with "no tool seated" while the status panel showed
    LOCKED and T0.
    Homing X sweeps the head across every dock position, so it has to run at a Y
    that clears the tools. A full G28 skipped the clearance move entirely, on the
    reasoning that a just-homed Y sits at the endstop. That only holds when the
    endstop is on the far side of the machine from the docks. Where it is not, the
    head parks in the dock row and then sweeps sideways through the other tools,
    with a seated tool's extra footprint making contact likelier. The move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
    [homing.cfg, indx-tc-macros.cfg]
2026-09-15 Refuse when the load cell and the saved tool disagree
    A user homed with T3 in the head and a load cell reading empty, and INDX went
    to fetch T0 with T3 still in the gripper.
    The seat check treated the cell as the authority: if it read empty, the saved
    tool number was wrong whatever it said, so active_tool was cleared and T0
    fetched. That premise is false in the case that matters. The cell reads empty
    if it was tared with a tool in the head, and then the saved number is the
    correct one and the cell is the liar. Clearing active_tool also skipped the
    park, so CHANGE_TOOL drove the loaded tool straight into another dock instead
    of putting it away first.
    Neither source can be trusted over the o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
    [homing.cfg]
2026-09-15 Document INDX heater smoothing interval
2026-09-16 Make the load-cell seat check opt-in, off by default
    The load cell is a dependable contact detector and an undependable scale.
    Probing asks it when force changed, which it answers well, and that is why it
    is the Z probe. The seat check asked it how many grams are on the head, and
    that number moves with the tare: a head tared with a tool already in it reads
    near zero with that tool still seated. A user hit exactly that and could not
    home a machine that was in a perfectly safe state.
    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
    [homing.cfg, indx-tc-macros.cfg, indx.cfg]
2026-09-16 Update reference model to INDX_simplified_1.19.step
    Adds open nozzle front geometry, so the nozzle front can be modified and
    printed rather than only used as supplied.
    Replaces 1.18. The README table now points at the new file and says what the
    geometry is for.
2026-09-18 Collapse the duplicated seat-check macros into one
    The seat is read twice on an empty-head G28, before and after the T0 pickup,
    and Klipper refuses to re-enter a macro still on the call stack. The earlier
    fix for that duplicated the read under a second name. Adding the opt-in seat
    check later duplicated a second pair the same way, and the error dispatch a
    third, so three near-identical pairs were being kept in step by hand.
    Charlie Mayall's PR #70 proposed the shape that avoids the copies: let the read
    return to its caller and have the caller dispatch. The second read then happens
    with the first already off the stack, so one macro serves both positions.
    _INDX_HOME_VERIFY now settles, reads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
    [homing.cfg]
2026-09-21 Home X where Y lands when that already clears the docks
    that clears the tools. The previous fix moved to clearance_y unconditionally
    after homing Y, because this template renders before G28 Y runs and the live
    toolhead position still reports the pre-home value.
    That was too blunt. A machine whose Y endstop sits opposite the docks is
    already clear when Y finishes homing, and further from the tools than
    clearance_y is. Moving it to clearance_y takes the head from a safe position
    to a closer one, and homes X somewhere the user did not ask for. On the
    machine that turned this up the Y endstop is at +93 with the docks a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
    [homing.cfg]
2026-09-21 Add MANUAL_TOOL_SEAT so a hand-placed tool can be claimed
    Z homing probes with the nozzle, so it needs a tool on the head. Every route
    to active_tool went through CHANGE_TOOL, which drives to a dock, which needs a
    homed Z. On a machine that has never homed Z the only way in is to place a tool
    by hand, and nothing recorded that it had happened: active_tool stayed -1 and
    homing refused a head with a tool sitting in it.
    The refusal even said "seat and lock a tool by hand, then G28 Z", which led
    straight back to the same error. With the seat check on it went to a different
    refusal, that the cell could see a tool but active_tool was unknown. Both dead
    ends, and MANUAL_TOOL_REMOVE had no counterp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
    [homing.cfg, indx-cal.cfg]
2026-09-21 G28 always homes Z on T0, and stops guessing at machine speeds
    Two changes to make the override do what is asked of it on any machine rather
    than only where its assumptions happen to hold.
    Z offsets are stored as differences from T0, so T0 is the only tool whose probe
    reading defines the origin instead of an offset from it. G28 now makes T0 the
    tool on the head before probing: an empty head fetches it, and any other tool
    is parked and swapped out. Homing on whichever tool happened to be seated saved
    a dock trip and put the origin on a tool that only knows its offset from T0.
    The z_known guard is gone with it. It refused to fetch T0 whenever Z had never
    been homed, on the reasoning that a d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
    [homing.cfg, indx.cfg]
2026-09-21 Read active_tool after homing, not before, and keep G28 off the tool-change stack
    Making G28 fetch T0 turned a latent problem in three macros into a live one.
    CHANGE_TOOL, PARK_TOOL and the homing override all read active_tool at render
    time and then called G28, which now changes the very value they had just read.
    CHANGE_TOOL and PARK_TOOL are split so the homing happens in the outer macro
    and the work is done by _CHANGE_TOOL_APPLY and _PARK_TOOL_APPLY, which render
    when they are reached and so see the tool homing left on the head. T0 from a
    cold start used to drive to the dock and drop the tool it had just collected,
    because the outer template still believed the head was empty. T1 from a c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
    [homing.cfg, indx-tc-macros.cfg]
2026-09-21 Add RESET_TOOL_OFFSETS
    Clearing every tool's XY and Z offset took nine SAVE_VARIABLE calls typed by
    hand, with the live gcode offset left holding the old numbers for whatever was
    on the head until the next pickup.
    RESET_TOOL_OFFSETS zeroes all of them for tool_count tools and reapplies the
    live offset so the machine agrees with what was just saved. Z keeps the global
    component, which belongs to RESET_GLOBAL_Z and is not this macro's to touch.
    The old values are printed before they go, in the same layout CAL_CHECK_OFFSETS
    uses, so a reset by mistake can be undone from the console rather than from
    another calibration run.
    MOVE=1 keeps the nozzle physically where it is, but Klipper needs a h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
    [indx-cal.cfg]
2026-09-29 Correct sizing and print orientation of a few STLs
    Correct orientation of CAD/STL/INDX Tool Dock 1515 Spring lid.stl
    Correct sizing (meters->millimeters) of community/1_printer_agnostic/2020-dock/[a]_magnet_holder_1x.stl and community/1_printer_agnostic/2020-dock/[a]_spring_lid_1x.stl
    [INDX Tool Dock 1515 Spring lid.stl, [a]_magnet_holder_1x.stl, [a]_spring_lid_1x.stl]
2026-10-06 INDX variables update
    [INDX_variables.g]
2026-10-06 Tool change macros
    [INDX_TC_FREE.g, INDX_TC_POST.g, INDX_TC_PRE.g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]
2026-10-06 example resurrect-prologue.g
    [resurrect-prologue.g]
2026-10-06 Updated Loadcell files
    [INDX_CLOSE.g, INDX_CLOSE_CAL.g, INDX_LC_CAL.g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]
2026-10-06 Other macro updates
    [INDX_LATCH_MOVE.g, INDX_OPEN.g, INDX_UNLOCK_DANCE.g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]
2026-10-06 Change Debug global variable name to INDX_DEBUG
    [INDX_CLOSE.g, INDX_CLOSE_CAL.g, INDX_LC_CAL.g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]
2026-10-06 added missing files
    [INDX_LATCH_ENGAGE.g, INDX_LC_SPEED_SWEEP.g, INDX_TC_TEST.g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]
2026-10-09 Don't drive into docks that were never calibrated (#88)
    * Don't drive into docks that were never calibrated
    On a fresh install the dock positions in indx.cfg are placeholders, and G28
    with an empty head fetches T0 from its dock (Z always homes on T0), so the
    very first G28 could drive the head into a dock position nobody measured.
    The README even had users run G28 right after the load cell calibration,
    with the tool removed.
    indx.cfg gets docks_calibrated: False. While it is False, CHANGE_TOOL,
    PARK_TOOL and a G28 that would fetch T0 refuse with what to do instead:
    put T0 on the head by hand, MANUAL_TOOL_SEAT TOOL=0, then G28. Once every
    dock is measured, set it True and RESTART. A missing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
    [homing.cfg, indx-tc-macros.cfg, indx.cfg]
2026-10-09 Check dock clearance before homing and tool changes; build the tools list before an early G28
    [homing.cfg, indx-tc-macros.cfg, indx.cfg]
2026-10-09 README: homing order after #82/#84, MANUAL_TOOL_SEAT, RESET_TOOL_OFFSETS, full RRF file list
2026-10-09 README: optional eddy current scanner config
2026-10-09 Turn the heater off at the park, after the queued print moves have finished
    [indx-tc-macros.cfg]
2026-10-09 Display alerts, raise cleanup, heat rules in M104/M109, clear the bed mesh when G28 starts with Z unhomed
    [homing.cfg, indx-tc-macros.cfg]
2026-10-09 Refuse load cell calibration with a tool on the head
    [indx-cal.cfg]
2026-10-09 Show the active tool on the Mainsail and Fluidd tool buttons
    [indx-cal.cfg, indx-tc-macros.cfg, indx.cfg]
2026-10-09 Check every pickup and park with the load cell
    [indx-tc-macros.cfg, indx.cfg]
2026-10-09 Document the pickup and park checks; clearer failure messages
    [indx-tc-macros.cfg]
2026-10-09 Keep a possibly half seated tool recorded after a failed pickup
    [indx-tc-macros.cfg, indx.cfg]
2026-10-09 Refuse homing and tool changes until a possibly half seated tool is checked
    [homing.cfg, indx-cal.cfg, indx-tc-macros.cfg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]
2026-10-09 Seat and park check thresholds 15 % more lenient: 680 g seated, 230 g empty, 425 g park change
    [indx-tc-macros.cfg, indx.cfg]
2026-10-09 A pickup retry in sport mode drops to normal speed and says so until MODE_SPORT is chosen again
    [indx-tc-macros.cfg]
2026-10-09 Pickup form no tool selected no longer selects old Z height
    [INDX_TC_FREE.g, INDX_TC_PRE.g]
2026-10-14 README: eddy scanner rapid scan, meshing practice, clearance and troubleshooting
    Kalico merged multiple probes (#972), rapid scan (#1007) and amplitude_errors (#1009) on 2026-10-08. Adds METHOD=rapid_scan, mesh with cold nozzles, level with the load cell, the screw head clearance and a troubleshooting table.
2026-10-20 Seat reading after a probe: count from the empty-head calibration
    INDX_STATUS and the G28 seat check read force_g, which counts from the last tare. Every probe or tap (G28 Z, LOAD_CELL_TEST_TAP) tares again with the tool on the head, so afterwards a seated tool rea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
